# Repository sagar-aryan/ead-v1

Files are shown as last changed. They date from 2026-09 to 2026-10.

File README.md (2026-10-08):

# EAD V1

A right-leg, barefoot wearable for gait research after stroke, built on error
augmentation. Two IMUs on the foot and shank detect every gait cycle; the device
scores each cycle against the wearer's own recorded baseline and, when a step is off,
cues it through six vibration motors on a calf band. A desktop dashboard records the
raw data, manages baselines and sessions, and exports CSV, MATLAB and PDF.

> Research and engineering prototype. Not a medical device and not a validated clinical
> tool.

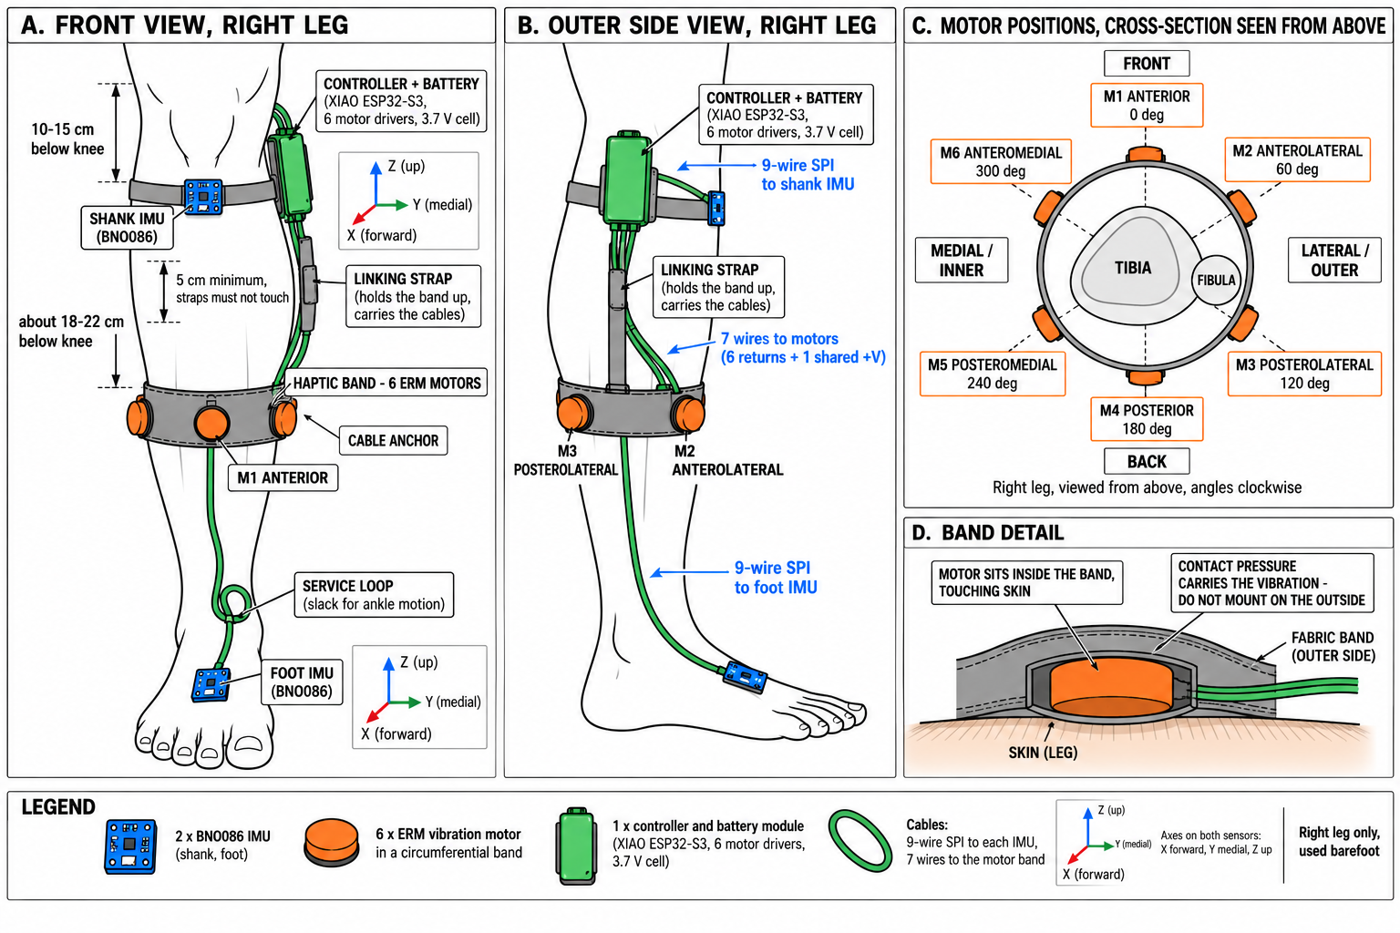
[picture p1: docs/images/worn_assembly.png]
Worn assembly: foot and shank IMUs, controller, and the six-motor calf band


*Illustration of the worn layout and motor positions. Exact placement and wiring:
[`docs/hardware.md`](docs/hardware.md), worn assembly.*

## How it works

```text
foot + shank BNO086 (SPI, 200 Hz)
  → XIAO ESP32-S3: orientation, gait events, zero-velocity updates, per-cycle score
  → vibration cue on the device (no laptop in the loop)
  → Wi-Fi access point or USB → dashboard (Tauri): live view, SQLite store, exports
```

- **Gait:** each right-leg cycle is found from the shank's swing; heel strike, toe-off,
  stance, swing, cadence, stride length and speed are computed on the device, with
  foot-flat zero-velocity updates to bound integration drift.
- **Score:** seven features (swing dorsiflexion, contact angle, inversion/eversion,
  cycle time, stance ratio, stride distance, shank swing rate) are compared with the
  baseline's medians and spreads and combined into one score from 0 to 1.
- **Cue:** a score of 0.35 or more starts a 0.5 s buzz, 60–100 % strength by how far off
  the step was. Where it buzzes names the error, on the side to move away from: the
  back of the calf for too little toe lift or a toe-first landing, the inner side for
  rolling onto the outer edge (inversion), the outer side for rolling in (eversion),
  front and back in turn for timing. The buzz stops at the first good step. On-time limits (5 s
  continuous, 50 % over any 10 s) are enforced on the device; sensor faults, a switched
  off feedback toggle, or 5 s without the laptop hold cues back.
- **Data:** every raw sample is kept. A 6 MB buffer on the device holds about 4.5 min,
  so a Wi-Fi dropout is filled in after reconnecting.

## Hardware

| Part | Detail |
|---|---|
| Controller | Seeed XIAO ESP32-S3 (plain, not Sense) |
| IMUs | 2 × 7Semi BNO086 breakout on SPI: foot (dorsum) and shank (anterior shin) |
| Haptics | 6 ERM coin motors around the calf, driven by the PCB in `hardware/erm-driver-pcb/` (tight variant): low-side MOSFETs, two 3.3 V regulators |
| Power | 1S Li-ion cell, charger module, master switch |

Every pin and connection, with its evidence: [`docs/wiring_reference.md`](docs/wiring_reference.md).
All 15 usable XIAO GPIOs are in use.

## Repository

| Folder | Contents |
|---|---|
| `firmware/` | Device firmware (PlatformIO, Arduino-ESP32); portable, host-tested core in `lib/ead_core` |
| `dashboard/` | Desktop app: Rust backend (device link, SQLite, exports) and React frontend |
| `hardware/erm-driver-pcb/` | KiCad project of the motor driver board, with its own docs |
| `protocol/vectors/` | Golden wire-protocol messages and their generator |
| `tools/` | `eadprobe.py` (independent device client), export checkers, walk replay |
| `recordings/` | Walk recordings with counted steps, used to test gait detection |
| `docs/` | Engineering docs: architecture, implementation, hardware, wiring, protocol, handoff |
| `ead_agent_docs_v2/` | The original V1 specification (read-only) |

## Getting started

**Prerequisites:** PlatformIO, Node.js 20+, a stable Rust toolchain, Python 3 with
pyserial (numpy and scipy for the export checker), and on Linux WebKitGTK 4.1.
`scripts/setup-linux.sh check` reports what is missing. Linux is the tested
platform; setup scripts for macOS and Windows are included.

**Firmware:**

```sh
pio run -d firmware -t upload        # build and flash over USB
python3 tools/eadprobe.py hello      # identity, protocol schema, firmware version
python3 tools/eadprobe.py check      # per-wire sensor check
```

The first build creates `firmware/include/ead_secrets.h` with a random Wi-Fi
passphrase. It is ignored by git; never commit it.

**Dashboard:**

```sh
cd dashboard && npm install
npx tauri dev                        # development
npx tauri build --no-bundle          # release build; see dashboard/README.md for `ead`
```

**Connecting:** over USB, or join the device's access point `EAD-V1-xxxx` (passphrase in
`ead_secrets.h`) and connect the dashboard to `ws://192.168.4.1:8080/ws`.

## Using it

1. **Calibrate:** stand still for 5 s with the sensors strapped on.
2. **Baseline:** walk normally on a straight path until at least 30 valid cycles
   (about 60 steps) are collected. Baselines are versioned per patient and locked.
3. **Check:** a short scored walk against the baseline.
4. **Evaluate:** walk with feedback on; the session's limits (cycles, errors) are set
   first.
5. **Export:** raw samples, cycles, events and cues as CSV, plus `metadata.json`,
   `session.mat` and a PDF report.

Calibrate after every restart. A baseline belongs to the strapping it was recorded
in, so record a new one after re-strapping the sensors.

## Testing

```sh
pio test -d firmware -e native                     # firmware core
(cd dashboard/src-tauri && cargo test)             # backend
(cd dashboard && npm test && npm run build)        # frontend
python3 tools/eadprobe.py vectors                  # protocol, against the golden vectors
```

On hardware, `eadprobe stats` and `cargo test hardware -- --ignored --test-threads=1`.

## Safety

- **Never turn the battery switch on while USB is plugged in.** Motor tests run on
  battery over Wi-Fi with USB unplugged.
- Motors are held off from power-up; GPIO39 must never drive a motor
  ([`docs/wiring_reference.md`](docs/wiring_reference.md) §10).

## Status

Working end to end, worn on battery over Wi-Fi: step detection, per-step scoring
against the wearer's own baseline, directional graded cues, and full raw-data export.
Current state and roadmap: [`docs/handoff.md`](docs/handoff.md).

## Documentation

Start with [`docs/handoff.md`](docs/handoff.md); [`docs/README.md`](docs/README.md)
indexes the rest, including the wire protocol ([`docs/protocol.md`](docs/protocol.md)).

## License

MIT ([`LICENSE`](LICENSE)): firmware, dashboard, tools, hardware design files and
documentation. Exceptions keep their own licences: the IBM Plex fonts in
`dashboard/src-tauri/assets/fonts/` (SIL Open Font License 1.1, `OFL.txt` beside them)
and the agent skills in `.claude/skills/` (Apache 2.0 and MIT, as each states). The
software comes with no warranty, and nothing here is cleared for clinical use.

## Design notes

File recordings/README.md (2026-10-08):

# Recordings

Real device recordings kept as fixtures, so the detector can be changed and
re-checked against measured ground truth instead of against a synthetic signal.

Replay one with:

```
g++ -std=gnu++17 -O2 -I firmware/lib/ead_core/src -I firmware/include \
    -o /tmp/eadreplay tools/replay/main.cpp \
    firmware/lib/ead_core/src/ead/{calibration,mahony,gait,protocol,crc32,cobs,feed}.cpp
/tmp/eadreplay recordings/walk6m-2026-09-18.eadlog --still-seconds 5 --mpu6500
```

A recording made by `eadprobe stats --record` since schema 5 carries the device's
configuration, and the replay converts its counts with it. Older recordings carry
none: `--mpu6500` supplies the MPU6500 build's scales and measured mount maps,
and without it the replay refuses rather than guess. Expected for the walk below:
5 valid cycles, 5.83 m (DEC-022).

| File | Ground truth | Notes |
|---|---|---|
| `walk10m-normal1-2026-10-02.eadlog` | 10.00 m course out and back; right-foot landings 9 out, 9 back | BNO086 build, normal pace. 6,500 frames. |
| `walk10m-normal2-2026-10-02.eadlog` | as above, 9 and 9 | Normal pace. 5,940 frames. Two short steps in the turn. |
| `walk10m-normal3-2026-10-02.eadlog` | as above, 9 and 9 | Normal pace. 6,660 frames. |
| `walk10m-slow-2026-10-02.eadlog` | as above, 11 and 11 | Slow pace. 6,050 frames. |
| `walk10m-fast-2026-10-02.eadlog` | as above, 8 and 8 | Fast pace. 4,770 frames. |
| `walk10m-normal1-2026-10-04.eadlog` | 10.00 m out and back; 8 right-foot landings per leg (walker's count) | Schema 6, 200 Hz, Wi-Fi, barefoot on carpet. `--still-from 8`. Video = data + 9.1 s. |
| `walk10m-normal2-2026-10-04.eadlog` | as above, 8 and 8 | `--still-from 7`. Video = data − 2.9 s. |
| `walk10m-normal3-2026-10-04.eadlog` | as above, 8 and 8 | `--still-from 0`. Video = data − 3.1 s. |
| `walk10m-slow1-2026-10-04.eadlog` | as above, 9–10 per leg; shank swings 10 and 9 | `--still-from 51.5`. Video = data − 2.7 s. |
| `walk10m-slow2-2026-10-04.eadlog` | as above, 9–10 per leg; shank swings 9 and 8 | `--still-from 33`. Video = data − 2.8 s. No stand between the stamps and the walk, or at the far end. |
| `walk10m-fast1-2026-10-04.eadlog` | as above, 7 per leg | `--still-from 37`. Video = data − 2.7 s. No stand at the far end. |
| `walk3min-2026-10-04.eadlog` | back and forth over the 10 m course for about 3 min; no per-leg count | `--still-from 187`. Video = data − 2.6 s. |
| `walk6m-2026-09-18.eadlog` (MPU6500 build: `--mpu6500`) | 6.00 m course, 11–12 alternating steps, 6 right-foot strides | 40 s over Wi-Fi: 5 s standing, the walk, then standing. 4,010 frames, no gaps. Heel strikes at 7.51, 9.17, 10.94, 12.74, 14.33 and 15.92 s; the acceleration peak at 6.95 s that TEST-030 also listed is the first step's push-off (TEST-059). |

The `walk10m-*` files are dashboard sessions written out by
`tools/session2eadlog.py` (TEST-052): the session's configuration, then its raw
frames, so the replay needs no flag. Worn by the developer (ID `DEV-1`), firmware
0.1.0+9c91b7d with the measured BNO086 maps; each starts and ends with about 5 s
standing, and has a stand, a turn and a stand between the legs. Replay with
`--still-seconds 5`, or all of them, with the 2026-10-04 walks, against their counts with
`tools/replay/walks.py /path/to/eadreplay`. Results per engine version are in
TEST-052 onward.

The `2026-10-04` files (TEST-058) start with the walker on the way from the laptop
to the start line, so calibrate from a still window with `--still-from S` (the
first 3 s window the replay accepts). Each walk has three right-heel stamps at the
start line before the first step, for syncing with its video; the stamps are not
steps. The videos are kept off the repository; the offsets above line a frame's
time in the video up with the recording's time.

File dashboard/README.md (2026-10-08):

# EAD V1 Dashboard

Tauri 2 + React + TypeScript + Vite + Rust desktop app for the EAD V1 right-leg
wearable. Contract: `../ead_agent_docs_v2/` docs 08, 10, 11 and 12. Stack
decision: DEC-011.

## Current state

Every doc 11 view except a separate HAPTICS page (cues are shown in CYCLES, EVENTS and
the state bar's vibration switch, DEC-023): LIVE, CYCLES, EVENTS, RAW, REFERENCES,
SESSIONS, EXPORT, DEVICE, and Check (`ead --check`). The Rust backend holds the device link
(USB or Wi-Fi, with backfill), the SQLite store, the session gate, host-side
segments and the export package (CSV, `metadata.json`, `.mat`, PDF).

## Prerequisites

- Node.js 20+ and npm
- Rust stable toolchain
- Tauri 2 Linux dependencies: WebKitGTK 4.1, libsoup 3 (WebView2 on Windows)

## Commands

```sh
npm install
npm run build                      # tsc + vite
(cd src-tauri && cargo build)      # Rust backend
npx tauri dev                      # run the app against the Vite dev server
npx tauri build --bundles deb      # Linux package
npm test                           # frontend logic tests
(cd src-tauri && cargo test)       # backend tests; -- --ignored needs the device
```

## The `ead` command

```sh
npx tauri build --no-bundle
ln -sf "$PWD/src-tauri/target/release/ead-dashboard" ~/.local/bin/ead
```

`ead` then opens the dashboard from any terminal, on the same database as
`tauri dev`. The link follows the build: rerun the first command after pulling
changes. Set up on the development machine on 2026-10-02.

## Icons

`app-icon.svg` is the source. After editing it run `npx tauri icon app-icon.svg`,
then delete the generated `android/`, `ios/`, `Square*Logo.png`, `StoreLogo.png`,
`64x64.png` and `icon.icns`. The app targets Linux and Windows desktops only.

## Data rule

Raw data is canonical and stored in full. Views receive downsampled or summarised
data only (doc 11 §3).

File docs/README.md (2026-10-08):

# EAD V1 — Engineering Documentation

Right-leg, barefoot, wearable error-augmentation system for stroke gait.
Source of implementation truth: `ead_agent_docs_v2/` (read-only contract).
This `docs/` tree records the engineering process: what was built, why, how it
evolved, and what was verified. Update it alongside every significant change.

## Index

- `handoff.md` — Start here: current state, milestone plan, how to run and verify.
- `protocol.md` — The device wire protocol: payloads, framing, backfill.
- `clinical_requirements.md` — The four clinical requirements: where each is
  specified, what is built, what is proven.
- `architecture.md` — Target system design, data flow, interfaces, dependencies.
- `implementation.md` — What exists in code today, per feature.
- `hardware.md` — As-built hardware: the current DEC-016 build, the previous
  MPU6500 build, register config, pins, mount maps.
- `wiring_reference.md` — Every connection of the DEC-016 build, with its evidence.

## Rules for contributors

- Contract values in `ead_agent_docs_v2/` override library defaults and intuition.
  Deviations need a DEC entry.
- Record approaches that were tried and replaced, with the reason.
- Record a test as passed only if it was run; include the measured numbers.
- Mark hardware facts as verified or unverified.

## Agent tooling

Project-level agent skills live in `.claude/skills/` (installed with the
`skills` CLI; pinned in `skills-lock.json`):
- `frontend-design`: UI design guidance.
- `vercel-react-best-practices`: React rendering-performance rules.

## V1 identity (summary)

- Right leg only, barefoot. Two IMUs at 200 Hz (100 Hz before schema 6, DEC-021). The product firmware drives two
  BNO086s on SPI (DEC-016, DEC-017) since schema 5; sessions recorded before it came
  from two MPU6500s on I²C (foot `0x68`, shank `0x69`).
- Six ERM motors on a calf band (DEC-015), fitted on the DEC-016 build (user,
  2026-10-02). Error-driven feedback during evaluations with the dashboard's switch on
  (DEC-023); service-test pulses outside sessions (DEC-018).
- The wire protocol between device and dashboard is implemented three times over
  (firmware, dashboard, `tools/eadprobe.py`), all checked against the same golden
  vectors in `protocol/vectors/`.
- Wi-Fi AP + WebSocket primary link, plus the same binary protocol over USB
  (DEC-005). No BLE, FSR or battery monitoring.
- Desktop: Tauri 2 + React + TypeScript + Rust, for observation, configuration,
  storage, analysis and export.

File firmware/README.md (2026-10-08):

# EAD-V1 Firmware

Seeed XIAO ESP32-S3 with two BNO086 IMUs on SPI (foot and shank) and six ERM motors
through the driver PCB, wired to DEC-016 (`../docs/wiring_reference.md`). Contract:
`../ead_agent_docs_v2/` (`CONFIG_V1.json` holds the fixed values). As-built hardware:
`../docs/hardware.md`. Wire protocol: `../docs/protocol.md`.

## Current state

Acquires both IMUs at 200 Hz, clocked by the foot gyroscope, with each sensor's own
orientation and a native 250 Hz accelerometer stream, and streams the binary
protocol over Wi-Fi and USB. About 4.5 minutes of telemetry is held in PSRAM so a host
can recover anything it missed.

On the device: static calibration, orientation per sensor, gait events from the
shank's swing, ZUPT and stride distance, cycle features, the reference builder, the
error engine and graded directional haptic cues (portable C++ in `lib/ead_core`, also
built on the host for tests and replay). Session kinds CALIBRATION,
REFERENCE_CAPTURE, REFERENCE_CHECK and EVALUATION; SERVICE_TEST pulses single motors
for the Check view.

## Layout

```text
firmware/
  platformio.ini        seeed_xiao_esp32s3 + native test env; gnu++17, no external libs
  include/config_v1.h   fixed V1 values, DEC-016 pins with compile-time checks, mount maps
  lib/ead_core/         portable: codec, COBS, CRC-32, message ring, config section,
                        SH-2 codec, calibration, Mahony, gait, reference builder,
                        error engine, haptics, motor guard
  src/bno086.*          SH-2 over SPI driver for both sensors
  src/acquisition.*     sensor reports, frame assembly
  src/motors.*          motor gates (LOW from boot), service-test pulses
  src/feedback.*        haptic cues during evaluations, on-time limits
  src/telemetry.*       durable message ring (PSRAM) and the processing task
  src/link.*            protocol endpoint: replies, status, streaming, backfill
  src/link_usb.*        USB Serial/JTAG transport (COBS framing)
  src/link_wifi.*       access point + WebSocket transport
  src/device.*          identity, faults, counters, HELLO/STATUS/CONFIG builders
  src/calibration_service.*  still-window calibration
  src/orientation.*     Mahony per sensor, quaternions into each frame
  src/gait_service.*    gait engine, EVENT_BATCH and STEP_BATCH
  src/session_service.* session kinds, reference capture, scoring
  bench/                not product: bno086 (DEC-016 pins), padstate
  test/                 Unity tests, run on the host against the golden vectors
  scripts/              build-time headers (firmware version, AP passphrase)
```

## Build, test and flash

```bash
pio run                 # build for the device
pio test -e native      # unit tests on the host
pio run -t upload       # flash over USB-C
```

## Talking to it

The USB port carries binary protocol frames, not text. Nothing in the firmware
may print to USB: a stray byte would corrupt a frame,
which is why `CORE_DEBUG_LEVEL=0` is a build flag and Arduino `Serial` is unused.

```bash
python3 ../tools/eadprobe.py hello     # identity, sequence window
python3 ../tools/eadprobe.py config    # configuration, hash-verified
python3 ../tools/eadprobe.py stats --seconds 60
```

Expect zero missing frames, zero dropped, zero rejected, and |a| ≈ 1.02 g on a
resting device.

## Wi-Fi access point

`EAD-V1-<last two MAC bytes>`, WPA2, channel 6, device at `192.168.4.1`,
WebSocket at `ws://192.168.4.1:8080/ws`. The passphrase is generated at first
build into `include/ead_secrets.h`, which git does not track; delete that file to
roll a new one.

## Wiring

DEC-016, every pin with its evidence: `../docs/wiring_reference.md`. Motors M1–M6 on
GPIO 4, 6, 42, 5, 2, 1 (DEC-029), held LOW as the first action at boot.

## Mount maps

`anat = M · chip`, applied to accel and gyro. Per-sensor maps are
measured on the leg (TEST-051) and kept in `include/config_v1.h`. A map that is not a
proper rotation fails to compile (DEC-009).

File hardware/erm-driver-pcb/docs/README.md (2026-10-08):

# EAS V1 — Six-Channel ERM Driver PCB

A single-sided, SMD-only, drill-free driver board for six 3 V ERM vibration motors in the EAS wearable. Two HT7833 LDOs make two isolated 3.3 V motor rails; six IRLML6344 low-side switches take PWM from a separate XIAO ESP32-S3. The specification is in `../EAS_ERM_Driver_PCB_Handoff/`; this folder records how it was implemented.

**In the EAD V1 repository since 2026-10-05** (`hardware/erm-driver-pcb/`), copied from
`~/Documents/ead pcb/` without the purchase invoices and KiCad's per-user files. The
**tight variant** (`EAS_ERM_Driver_tight/`, 36.07 × 27.60 mm) is the board fitted on
the device (user, 2026-10-05). The device as a whole is described in `../../../docs/`
(`hardware.md`, `wiring_reference.md`); the notes below are this board's own record,
as written.

## Status (2026-09-22)
- **Four layout variants, all verified in software:** ERC 0, DRC 0 violations, 0 unconnected, 0 schematic-parity issues, and every `check.py` handoff check passes.
- **The tight variant is built and drives the six motors on the device.**

| Variant | Folder | Board | Layout | 0 Ω jumpers |
|---|---|---|---|---|
| Single row (original) | `EAS_ERM_Driver/` | 82.75 × 19.00 mm (1572 mm²) | one row of 6 channels (DEC-013) | **none** |
| Compact | `EAS_ERM_Driver_compact/` | **44.70 × 32.60 mm** (1457 mm²) | two rows of 3 channels (DEC-016) | **none** |
| Mini | `EAS_ERM_Driver_mini/` | **38.91 × 29.28 mm** (1139 mm²) | two rows of 3, relaxed rules (DEC-017) | **none** |
| Tight | `EAS_ERM_Driver_tight/` | **36.07 × 27.60 mm** (996 mm²) | mini + 0.3 mm gaps and tight courtyards (DEC-018) | **none** |

All variants share the same circuit, parts and schematic content. Single row and compact also share footprints and rules and differ only in layout. The mini uses the standard (smaller) lands, a 0.4 mm gap around wire pads, a 0.5 mm edge margin and 1.0 mm power trunks (user-approved). The tight variant additionally uses 0.3 mm copper gaps and tight part courtyards. Choose one to fabricate.

| Common item | Value |
|---|---|
| Copper | one layer (F.Cu); no vias, no holes, no jumpers |
| Parts | 46 SMD parts + 18 SMD wire pads (no connectors) |
| Etch rules | 0.4 mm minimum track and gap; 0.5 mm pour clearance. Single row / compact: 0.6 mm around wire pads, 1.0 mm copper-to-edge, 1.5 mm power trunks, hand-solder lands. Mini: 0.4 mm, 0.5 mm, 1.0 mm, standard lands |

## Power rails
| Net | Source | Feeds | Copper |
|---|---|---|---|
| `SWITCHED_SYSTEM+` | wire pad `PWR+`, from the external master switch on the MCP73833 LOAD+ side (never raw BAT) | U1 and U2 VIN (SOT-89 tab), pad `ESP+` | 1.5 mm strip up the left edge (single row: also along the top edge to U2; mini: 1.0 mm) |
| `HAPTIC_3V3_A` | U1 HT7833 | motors 1–3 (pad `A+`), C5 1 µF, C7 220 µF, C15–C17 100 nF | 1.0 mm bus |
| `HAPTIC_3V3_B` | U2 HT7833 | motors 4–6 (pad `B+`), C6 1 µF, C8 220 µF, C18–C20 100 nF | 1.0 mm bus |
| `GND` | wire pad `GND` | everything | 1.5 mm bus under each channel row (mini: 1.0 mm), a 1.0 mm tooth per channel (mini: 0.8 mm), and pour (compact and mini: the two row buses are joined down the right edge) |

The two 3.3 V rails are never connected on the board. `check.py` confirms this, and DRC would flag any short.

## Wire pad map
Labels are as printed on the assembly drawings. Positions are pad centres in mm from the top-left corner of the outline.

| Drawing label | Ref | Net | Connect to | Pad (mm) |
|---|---|---|---|---|
| `PWR+` | J1 | SWITCHED_SYSTEM+ | master switch output (charger LOAD+ side) | 3.0 × 2.5 |
| `GND` | J2 | GND | charger LOAD− / system ground | 3.0 × 2.5 |
| `ESP+` | J3 | SWITCHED_SYSTEM+ | XIAO **battery** input (`ESP_SW_BAT+`). **Not** the XIAO 3V3 pin | 2.0 × 2.0 |
| `EGND` | J4 | GND | XIAO GND | 2.0 × 2.0 |
| `PWM1`…`PWM6` | J5–J10 | PWM1–6 | XIAO GPIOs | 2.0 × 2.0 |
| `A+` | J11 | HAPTIC_3V3_A | + leads of motors 1–3 (up to 3 wires) | 2.5 × 7.0 |
| `M1-`…`M3-` | J12–J14 | M1-…M3- | − lead of motors 1–3 | 2.5 × 2.5 |
| `B+` | J15 | HAPTIC_3V3_B | + leads of motors 4–6 (up to 3 wires) | 2.5 × 7.0 |
| `M4-`…`M6-` | J16–J18 | M4-…M6- | − lead of motors 4–6 | 2.5 × 2.5 |

Pad centres (mm from the top-left corner of the outline; each variant's full list is in its `output/check.txt`):

| Pads | Single row | Compact | Mini | Tight |
|---|---|---|---|---|
| J1 `PWR+`, J2 `GND` | (2.5, 16.8), (6.2, 16.8) | (2.5, 30.4), (6.2, 30.4) | (2.0, 27.5), (7.8, 27.5) | (2.0, 25.9), (7.6, 25.9) |
| J3 `ESP+`, J4 `EGND` | (2.0, 14.2), (9.2, 17.0) | (2.0, 27.9), (9.2, 30.6) | (4.9, 26.4), (10.7, 27.8) | (4.8, 24.8), (10.4, 26.1) |
| `PWM1`–`PWM3` | y 14.9; x 16.7, 26.1, 35.6 | y 13.0; x 16.7, 26.1, 35.6 | y 12.0; x 14.8, 22.9, 31.1 | y 11.3; x 14.1, 21.5, 28.9 |
| `PWM4`–`PWM6` | y 14.9; x 55.0, 64.4, 73.9 | y 28.5; x 16.7, 26.1, 35.6 | y 26.4; x 14.8, 22.9, 31.1 | y 24.8; x 14.1, 21.5, 28.9 |
| `A+` | (13.4, 6.7) vertical | (13.4, 4.8) vertical | (10.2, 4.0) vertical | (9.8, 4.0) vertical |
| `M1-`–`M3-` | y 9.9; x 16.8, 26.2, 35.6 | y 8.1; x 16.8, 26.2, 35.6 | y 7.2; x 15.6, 23.7, 31.8 | y 6.9; x 14.5, 21.9, 29.4 |
| `B+` | (59.7, 2.2) horizontal | (13.4, 20.3) vertical | (10.2, 18.3) vertical | (9.8, 17.4) vertical |
| `M4-`–`M6-` | y 9.9; x 55.0, 64.5, 74.0 | y 23.6; x 16.8, 26.2, 35.6 | y 21.6; x 15.6, 23.7, 31.8 | y 20.4; x 14.5, 21.9, 29.4 |

- **Board edge:** only the four power/ESP-power pads sit at the edge. The PWM and M- pads are enclosed by a GND or rail trace, so their wires pass over that trace (DEC-003). Use insulated wire and glue it down for strain relief.
- **Channel mapping:** PWMn drives Mn- (n = 1…6). The motor sits between A+ (or B+) and its Mn- pad.

## Rebuild and verify
```bash
cd EAS_ERM_Driver && bash scripts/export.sh            # single-row variant
cd EAS_ERM_Driver_compact && bash scripts/export.sh    # compact variant
cd EAS_ERM_Driver_mini && bash scripts/export.sh       # mini variant
cd EAS_ERM_Driver_tight && bash scripts/export.sh      # tight variant
```
Each run rebuilds from its own `scripts/build.py`, then runs ERC, DRC+parity, `check.py` and all exports, and stops on any failure.
- **Requirements:** KiCad 10.0.6 (`kicad-cli` and the `pcbnew` Python module), Python 3, poppler `pdftoppm`, Pillow.
- **To inspect:** open `EAS_ERM_Driver*.kicad_pro` in KiCad 10; the files are not readable by KiCad ≤ 9.

## Outputs (`<variant folder>/output/`, file names prefixed with the project name)
| File | Use |
|---|---|
| `*_TONER_F.Cu_MIRRORED_print_1to1.pdf` | **print this for toner transfer**, at 100 % scale (one copy) |
| `*_TONER_PANEL_6up_MIRRORED_print_1to1.pdf` | tight and mini variants: six copies on one A4 sheet, 30 mm apart, with a printed ruler to confirm the print scale (DEC-020). Any other grid: `scripts/panel.py <cols> <rows> [gap mm]` (it is not produced by `export.sh`, which clears `output/`) |
| `*_PANEL.kicad_pcb` | throwaway board the panel PDF is plotted from; regenerate it with `scripts/panel.py`, never edit it |
| `*_F.Cu_top_view_fitcheck_1to1.pdf` | unmirrored top view; lay the real parts on it before etching |
| `*_placement_3to1.pdf` | **place parts from this one**: part outlines, reference + value, pad labels and legend, without pad numbers |
| `*_assembly_1to1.pdf`, `*_assembly_3to1.pdf` | the same drawing with the pads and their pin numbers sketched; use it to identify pin 1 on U1/U2 and Q1–Q6. The pad digits overlap some labels, which is why `*_placement_3to1.pdf` exists |
| `*_schematic.pdf` | schematic |
| `*_bom.csv` | BOM |
| `gerbers/` | F.Cu and Edge.Cuts Gerbers (no drill file: zero holes) |
| `erc.rpt`, `drc.rpt`, `check.txt` | verification reports; `check.txt` contains the full connection summary and pad map |
| `preview_*.png` | quick-look images |

## Documentation index
- `architecture.md`: system and board structure.
- `implementation.md`: how the build scripts generate the design.
- `hardware.md`: BOM, pinouts, footprints, thermal, fabrication and assembly.
- `decisions.md`: DEC-001…DEC-020.
- `handoff.md`: how to continue.

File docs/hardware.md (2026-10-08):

# Hardware (as built)

Contract values come from `ead_agent_docs_v2/02_HARDWARE_WIRING.md`,
`03_GPIO_PIN_MAP.md` and `17_HARDWARE_BOM_AND_OWNED_PARTS.md`. This file records
what the physical unit actually is, how it deviates, and what has been verified.
Every row states its evidence; "unverified" means nobody has measured it yet.

## Current build: DEC-016 (2026-10-02)

| Item | State | Evidence |
|---|---|---|
| Wiring | DEC-016 exactly: two BNO086 on SPI, six motor channels, two HT7833 rails, battery. Every connection in `docs/wiring_reference.md` §3–§11 | User, 2026-10-02, against `EAD_V1_XIAO_connections.pdf` (whose pins match DEC-016) |
| Parts fitted | Everything, including the six motors | User, 2026-10-02 |
| Motors | Tested by the user with a PWM signal | User, 2026-10-02 |
| Powered | Yes, since assembly | User, 2026-10-02 |
| Which XIAO | The one measured in TEST-041: USB serial number (= MAC) `44:B1:76:AF:FB:7C` | Read from the USB descriptor, 2026-10-02 |
| Firmware on it | The product firmware, schema 5 (`5b8dd28` and later), on the DEC-016 pins. Before that, `padstate`, which booted on the new wiring (TEST-044) | HELLO, 2026-10-02 |
| ERM driver | Separate PCB, `hardware/erm-driver-pcb/` (`~/Documents/ead pcb/` until 2026-10-05), the **tight variant** fitted (`EAS_ERM_Driver_tight/`, 36.07 × 27.60 mm; user, 2026-10-05): Holtek HT7833 SOT-89 ×2, IRLML6344 ×6, 1N5819W, 100 Ω / 100 kΩ, 10 nF across each motor, 100 nF per channel. Motors rated 3 V, 90 mA, 120 mA at start. Its bring-up on 2026-09-24 ran the motors at 20 kHz PWM from GPIO1–6 (`erm_channel_test.ino`); a stuck-motor event there has no established root cause | PCB project docs |
| Measured on the assembled build | Both BNO086s pass every wiring, identity and data check at 1 MHz (TEST-043). Pad readback: GPIO42 (motor 3) read low, unlike the other five; MTMS measured about 100 kΩ to GND (user), the correct gate network | TEST-043, TEST-044, user |
| XIAO power | The switched LOAD+ feeds the ERM driver's PWR+ **and the XIAO's 5V (VUSB) pin**, not its BAT+ pad. **The XIAO has no diode on that pin**, so with USB plugged in, USB 5 V sits on the switched node: switch OFF, it powers the ERM driver (motor rails live); switch ON, it meets the charger's LOAD+ | User, 2026-10-02; Seeed XIAO ESP32-S3 wiki |
| Foot cable | About 30 cm | User, 2026-10-02 |
| Charger | SmartElex MCP73833 module (Robocraze): USB mini-B, 500 mA default charge, separate battery and load connectors. The cell has its own protection board (user, 2026-10-04) | User, 2026-10-02 and 2026-10-04; product page |

**Only firmware on the DEC-016 pins goes on this build:** the product firmware from
`5b8dd28` on, `firmware/bench/bno086`, or `padstate`. Product firmware from before
`5b8dd28` uses the doc-03 pins: it would run I²C bus recovery and `Wire` on GPIO5/6
(motor gates 5 and 6) and drive GPIO9 (MOSI), 43 and 44 (both chip selects) LOW as
motors.

`padstate` is not harmless on this build either: at each boot its readback switches
each pin's internal pull-up on for 0.3 ms, which on a motor pin puts about 2.3 V on
the gate (the DEC-016 GPIO39 reasoning) and switches that MOSFET on for 0.3 ms. That
is far too short to spin an ERM.

The sections below describe the previous build (MPU6500 on I²C, 2026-09-17 to
2026-10-01), on which every recording and dashboard session so far was made.

## Controller

| Item | Value | Evidence |
|---|---|---|
| Board | Seeed XIAO ESP32-S3 | PlatformIO env `seeed_xiao_esp32s3` |
| Flash / PSRAM | 8 MB / 8 MB (OPI) | Board definition (`-DBOARD_HAS_PSRAM`, `qio_opi`); PSRAM present on this unit (`eadprobe hello`: `psram_ring`) |
| USB | Native USB Serial/JTAG, VID:PID `303a:1001`, serial number = Wi-Fi MAC `44:B1:76:AF:FB:7C` | `lsusb` / `udevadm`, 2026-09-17 |
| Partition table | `default_8MB.csv`: 2 × 3.2 MB app slots, 1.5 MB data (`spiffs`), 64 KB coredump | Arduino-ESP32 2.0.17 package |
| Wi-Fi antenna | Seeed recommends fitting the supplied U.FL antenna for usable Wi-Fi range | Seeed wiki (accessed 2026-09-17) |
| Power | Battery-powered and wearable (user, 2026-09-17). Firmware has no battery or charger logic (spec) | User statement |

## IMUs (previous build)

Both breakouts were sold as MPU6050 but carry **MPU6500** silicon.

| Sensor | I²C address | WHO_AM_I | Evidence |
|---|---|---|---|
| Foot (dorsum) | `0x68` (AD0 → GND) | `0x70` | Boot log 2026-09-17 |
| Shank (anterior shin) | `0x69` (AD0 → 3V3) | `0x70` | Boot log 2026-09-17 |

Register configuration written at boot and verified by readback on both sensors
(boot log + `c` diagnostics, 2026-09-17):

| Register | Address | Value | Meaning |
|---|---|---|---|
| PWR_MGMT_1 | 0x6B | 0x01 | Awake, PLL clock source |
| SMPLRT_DIV | 0x19 | 0x09 | 1 kHz / 10 = 100 Hz output |
| CONFIG | 0x1A | 0x03 | Gyro DLPF ≈ 41–42 Hz |
| ACCEL_CONFIG2 | 0x1D | 0x03 | Accel DLPF ≈ 41 Hz (MPU6500 only) |
| GYRO_CONFIG | 0x1B | 0x08 | ±500 °/s, 65.5 LSB/(°/s) |
| ACCEL_CONFIG | 0x1C | 0x08 | ±4 g, 8192 LSB/g |
| INT_PIN_CFG | 0x37 | 0x00 | Active-high, push-pull, 50 µs pulse |
| INT_ENABLE | 0x38 | 0x01 | Data-ready interrupt |

Observed at rest on a desk (not worn), 78 samples over 7.8 s, 2026-09-17:
foot |a| = 1.024 g, shank |a| = 1.014 g, accel σ ≤ 0.002 g, gyro offsets up to
3.1 °/s (foot X) and 2.0 °/s (shank Y). The offsets are ordinary MEMS gyro bias;
startup calibration (milestone M3) removes them.

## Pin map of the previous build (doc 03)

The current build's pin map is DEC-016, in `docs/wiring_reference.md` §3.

| Function | XIAO pin | ESP32-S3 GPIO | Status |
|---|---|---:|---|
| I²C SDA | D4 | 5 | Verified: both IMUs enumerate |
| I²C SCL | D5 | 6 | Verified: both IMUs enumerate |
| Foot IMU INT | D8 | 7 | Verified (TEST-015) |
| Shank IMU INT | D9 | 8 | Verified (TEST-015) |
| Motor 1 PWM | D0 | 1 | Held LOW (MPU6500 build) |
| Motor 2 PWM | D1 | 2 | Held LOW (MPU6500 build) |
| Motor 3 PWM | D3 | 4 | Held LOW (MPU6500 build) |
| Motor 4 PWM | D10 | 9 | Held LOW (MPU6500 build) |
| Motor 5 PWM | D6 | 43 | Held LOW (MPU6500 build) |
| Motor 6 PWM | D7 | 44 | Held LOW (MPU6500 build) |

## Sensor mounting and axis maps

The anatomical frame (doc 04 §1) is X forward toward the toes, Y medial (left for
the right leg), Z up. It is right-handed, and so is the MPU chip frame, so each
sensor's chip → anatomical map must be a proper rotation (determinant +1).
`firmware/include/config_v1.h` stores the maps as signed-permutation matrices and
rejects anything else at compile time.

| Sensor | Physical mounting | Map (anat = M · chip) |
|---|---|---|
| Foot | Flat on the dorsum, chip X toward the toes, chip Z up | Identity |
| Shank | Strapped to the anterior shin; chip +Z toward the bone (posterior); chip +X up the leg | `X = −chipZ`, `Y = +chipY`, `Z = +chipX` |

Derivation of the shank map: measured on the leg (TEST-027, 2026-09-17). Under the
previous map (`X = −chipZ`, `Y = +chipX`, `Z = −chipY`) standing still put gravity
on anatomical Y (+0.99 g) and a seated knee extension turned about anatomical Z
(+43 °/s) — anatomical Y and Z were interchanged. Correcting the measurement
(`Z_true = Y_measured`, `Y_true = −Z_measured`) gives the map above, which is still
a proper rotation. The earlier derivation assumed chip +Y points down the leg; the
board is in fact strapped with chip +X up the leg.

**Placement image.** `reference_images/RIGHT_LEG_IMU_PLACEMENT.png` sets the
anatomical convention; the shank board's chip axes in this table are the as-built
record, measured on the leg (DEC-009).

**Verification status.** Compile-time proper-rotation checks pass, including a
negative test with a reflected map. The shank map above was measured on the leg
(TEST-027) and flashed; re-running the mounting check with it is the confirmation
step. The foot map was confirmed on the leg: gravity dominant on +Z, the board
tilted about 33° on the instep, which calibration removes.

### BNO086 boards (DEC-016 build)

The table above is the MPU6500 build. The BNO086 maps were measured on the leg
(TEST-051, 2026-10-02) and agree with the user's description of the silkscreen
axes as worn:

| Sensor | Described by the user | Measured map (anat = M · chip) |
|---|---|---|
| Foot | chip x medial, chip y back toward the shank, chip z up | `X = −chipY`, `Y = +chipX`, `Z = +chipZ` |
| Shank | chip z out of the shin, chip x medial, chip y up the leg | `X = +chipZ`, `Y = +chipX`, `Z = +chipY` |

The foot board sits about 42° off level on the instep (standing gravity
(0.29, 0.62, 0.76) g in the chip frame); calibration removes the tilt.

## Haptics

**Current (DEC-016 build):** the six ERM channels and motors are fitted on the
separate driver PCB (user, 2026-10-02) and all six were felt at 50 % duty in service
pulses (TEST-049). The firmware drives the motor GPIOs LOW first in `setup()`, then
runs 200 Hz PWM for service pulses (DEC-018) and feedback cues during evaluations
(DEC-023). Cues were felt while walking on battery over Wi-Fi (TEST-066); since
DEC-026 cues run 60–100 % (153–255) for 500 ms.

**History:** on the MPU6500 build the channels were not fitted (user, 2026-09-17), and
DEC-006 kept all PWM and haptic code out of the firmware until they were.

## Hardware notes

- **Sensor ranges:** the BNO086 build runs at ±8 g and ±2000 °/s (TEST-040).

## BNO086 bench test (one sensor, SPI)

A single BNO086 breakout (7Semi, CEVA/Hillcrest SH-2) wired to a XIAO ESP32-S3 for
bring-up. Edge pins only, so nothing has to be soldered to the pads under the board.
This is the bench layout; it is not the product pin map, because D0–D3 are the
motor outputs in the product.

| Function | XIAO pin | ESP32-S3 GPIO |
|---|---|---:|
| 3V3 | 3V3 | — |
| GND | GND | — |
| SPI SCK | D8 | 7 |
| SPI MISO | D9 | 8 |
| SPI MOSI | D10 | 9 |
| CS | D3 | 4 |
| INT | D2 | 3 |
| RST | D1 | 2 |
| WAKE (= PS0 net on this board) | D0 | 1 |

PS0, PS1, BOOT, SDA, SCL and both Qwiic connectors are left unconnected. The board's
PS0/PS1 solder jumpers were opened by the user, so the on-board pull-ups hold both
high at reset and the part comes up in SPI mode; its I²C connectors no longer work.
WAKE and PS0 are the same net, so WAKE must be driven high before reset is released,
or the part would latch a UART mode instead.

Measured on this board, 2026-09-23 (TEST-039):

- Line readback (ESP32 pull-up / pull-down, sensor held in reset): CS 1/0 (floating,
  as expected); SCK, MISO and MOSI all 1/1, because on the BNO086 those are the same
  chip pins as SCL, SDA and SA0, which carry the breakout's I²C pull-ups. 0/0 on any
  line would mean it is held low: a short to ground or a wire on the wrong pin.
- INT is high while RST is held low, and goes low 112–115 ms after reset is released.
- SH-2 opens at 3 MHz, SPI mode 3.
- Product ID: 4 entries, the application firmware being part 10004563, version
  3.12.6, build 62, reset cause 4 (external reset — the RST pulse).
- Feature probe: ARVR-stabilised RV, gyro-integrated RV, stability classifier,
  magnetometer and tap detector all accept a set-feature request.
- Pulling WAKE low with no reports enabled made the sensor assert INT within 1 ms.
- At rest: |a| = 9.752 m/s² over 249 accelerometer reports, |ω| = 0.005 rad/s over
  199 gyro reports. Rotation vector, accelerometer and gyro stream together at
  99.9 Hz (2952 samples over 29.5 s).
- The product uses the game rotation vector (6-axis), which needs no magnetometer:
  tilt is referenced to gravity, heading is relative.

### What the BNO086 says about its own hardware (TEST-040, 2026-09-23)

| Reading | Value |
|---|---|
| Accelerometer | `Bosch Sensortec BMA280`, range 20082 (Q8 → 78.4 m/s² = ±8 g), q = 8 |
| Gyroscope | `Bosch Sensortec BMI055`, range 17863 (Q9 → 34.9 rad/s = ±2000 °/s), q = 9 |
| Magnetometer | `Bosch Sensortec BMM150`, range 32000, q = 4 |
| Rotation vector | range 16384, q = 14 |
| Oscillator | external crystal |
| FRS serial number | record present, empty |
| Interactive Calibration (BNO086 only) | Motion Intent accepted, Motion Request report accepted |
| Accelerometer resolution | 1120 steps per g over ±8 g = 14.1 bits (14-bit fusion is BNO086 only) |

Raw accelerometer counts come out as multiples of 4: the BMA280's 14-bit value sits
left-aligned in a 16-bit field.

### The bench project on the DEC-016 wiring (2026-10-02)

The one-sensor bench wiring above no longer exists: the user reported on
2026-10-02 that the XIAO is now wired to DEC-016 with everything soldered. On that
wiring the old bench pins D0, D1 and D3 are motor gates 1, 2 and 4, so
`firmware/bench/bno086` was moved to the DEC-016 pins:

- One sensor per build: `-e foot` (CS GPIO43, INT GPIO39) or `-e shank` (CS GPIO44,
  INT GPIO40); RST GPIO41 and WAKE GPIO3 are shared. The SparkFun library cannot
  drive two sensors at once: its pins are file-scope globals and CEVA's `sh2.c`
  inside it has one global instance (read in the library source, v1.0.6).
- First action: the six motor gates (GPIO1, 2, 42, 4, 5, 6) LOW, then both CS high.
  A `static_assert` refuses any build that puts a sensor line on a motor pin.
- SPI at 1 MHz (`docs/wiring_reference.md` rule 5), not the 3 MHz used on the bench.
- Also reports whether the other sensor's INT is high in reset and low after the
  shared RST is released, without talking to it.

Run on hardware: both sensors pass (TEST-043).

## Connection reference

`docs/wiring_reference.md` carries every electrical connection in one place:
the XIAO's full pin map, both BNO086 pinouts, the six ERM motor channels, the
haptic rails, the harnesses and the power input, each connection marked with
the evidence behind it. It is the document to hand to whoever builds the board.

## Worn assembly (DEC-015)

Worn assembly: foot IMU, shank IMU, controller and the six-motor band

*`docs/images/worn_assembly.png`. Illustration of the worn layout. As built: the
controller sits on the outer side of the right leg (panel B); the motor cable has 8
wires, since each half of the band has its own positive rail
(`docs/wiring_reference.md` §11). Checked against the contract: the six motor angles
and their clockwise order, the fibula on the lateral side, M2 toward the toes and M3
toward the calf in the side view, and both sensor axis triads.*

Two separate straps on the right shank, plus the foot module; worn on battery over
Wi-Fi since 2026-10-05 (TEST-066).

| Item | Position | Notes |
|---|---|---|
| Shank IMU (BNO086) | Anterior shin, 10–15 cm below the knee, on the upper strap | Doc 01 §2 |
| Controller + battery | Lateral side of the same upper strap | Position not specified by the contract; chosen to keep every cable short except the foot run |
| Six ERM motors | Lower strap, around the fullest part of the calf, below the upper strap | Angles per doc 06 §7: M1 anterior 0°, then clockwise viewed from above |
| Foot IMU (BNO086) | Dorsum of the foot, midfoot, lying flat | Doc 01 §2 |

Cable runs: 9 conductors to the shank IMU (3V3, GND, SCK, MISO, MOSI, CS, INT,
RST, WAKE), 10 to the foot IMU (the same plus a second ground beside SCK, for
the long run), and **8 to the motor band**: six switched returns, one positive
from haptic rail A for M1–M3, and one from rail B for M4–M6. The two rails come
from separate regulators whose outputs must never be joined
(`ead_agent_docs_v2/02_HARDWARE_WIRING.md` §5). An earlier revision said 7 with
one shared positive; that would have tied the two regulator outputs together.

Practical points for the build, none of them yet verified on a leg:

- Leave at least 5 cm between the two straps, and do not let them touch: touching
  straps couple vibration mechanically, on top of what travels through tissue.
- The calf tapers below its fullest point, so the motor band will tend to slide
  down. A short vertical strap between the two bands, doubling as the cable
  channel, holds it up.
- Anchor the foot cable to the **motor** band before it runs down the shin. A tug
  on that cable must not reach the IMU strap, because rotating that strap
  invalidates the shank mount map mid-session.
- Keep the controller enclosure on the lateral side, off the tibia, and tight
  enough not to bounce; its mass sits on the same strap as the IMU.
- Leave slack in the strap-to-strap wiring: calf circumference changes as the
  muscle contracts.

## Power budget (estimate, 2026-10-05; not measured)

The battery switch is never ON while USB is plugged in (user, 2026-10-05), so the
battery current can only be measured in series with the cell, or as a runtime test.

| Load | Current at the battery | Source |
|---|---|---|
| XIAO ESP32-S3, Wi-Fi AP streaming ~23 kB/s, CPU 240 MHz (firmware sets neither clock nor TX power) | 100–150 mA average; TX bursts to ~340 mA | Seeed wiki: ~100 mA Wi-Fi active; Espressif ESP32-S3 datasheet ranges for TX/RX |
| BNO086 ×2, accelerometer + gyroscope + game rotation vector at 200 Hz | 10–15 mA each | ~12.3 mA awake measured by a third party (wolles-elektronikkiste.de); our report set not measured |
| ERM ×6 via HT7833 (LDO, so battery current ≈ motor current) | 90 mA rated per motor at 3 V, 120 mA start; × PWM duty × on-time | `docs/hardware.md` ERM driver row |
| Cues (DEC-023): 250 ms per ~1.2 s cycle | typical ~3 mA (one motor, ~50 % duty, 30 % of steps); worst ~30 mA (two motors, 80 %, every step) | arithmetic |

Totals: ~125–190 mA streaming without cues, ~155–220 mA at worst-case feedback; peak
~610 mA. With 1.6–1.8 Ah usable from a ~2 Ah cell: **about 8–14 h** without cues,
**7–12 h** at worst-case feedback.

To be confirmed by measurement: the usable capacity (the XIAO's 3.3 V regulator is fed
from the 5V pin at cell voltage), the cell's real capacity, and the AP-mode average. A runtime test settles it: full charge, stream over Wi-Fi with
the dashboard recording until the device stops; the session's last frame is the runtime.

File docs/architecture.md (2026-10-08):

# Architecture

This is the target design. What is implemented today is tracked in
`docs/implementation.md`; as-built hardware facts are in `docs/hardware.md`.

## Overview

EAD V1 is a right-leg, barefoot, wearable error-augmentation system for gait
monitoring and retraining after stroke (`ead_agent_docs_v2/01_SYSTEM_SPEC.md`).
Two IMUs (foot + shank) feed a 200 Hz real-time loop on a XIAO ESP32-S3 (100 Hz
before schema 6). Orientation comes from each BNO086's own fusion (game rotation
vector, DEC-021; Mahony 6-DoF on the ESP32 before schema 6). The loop detects gait events, applies
foot-only ZUPT correction, and scores each gait cycle against a patient-specific
reference. A Tauri 2 desktop dashboard observes, configures, records, analyses
and exports; it never closes a control loop.

Haptic feedback runs on the device during an EVALUATION session with the dashboard's
master switch on: one cue per scored cycle, after the step lands (DEC-023). Outside a
session the motors run only as service-test pulses (DEC-018).

The hardware is the DEC-016 build: two BNO086 on SPI plus six motor channels on a
separate ERM driver board, with the haptic band on the calf (DEC-015). The product
firmware supports it since schema 5 (DEC-017). The MPU6500/I²C build it replaced is
described at the end of the components, because every recording before 2026-10-02
came from it.

## Components

### Foot and shank sensors (BNO086, DEC-016/017)
- Foot: dorsum of the right foot; CS GPIO43, INT GPIO39. Shank: anterior shin,
  10–15 cm below the knee; CS GPIO44, INT GPIO40.
- One SPI bus (SCK 7, MISO 8, MOSI 9, 1 MHz, mode 3); RST (41) and WAKE (3) shared.
- Calibrated accelerometer (±8 g, 250 Hz), gyroscope (±2000 °/s, 200 Hz) and game
  rotation vector (200 Hz) reports, read on INT by our own SH-2 code
  (`src/bno086.cpp`, `lib/ead_core/src/ead/sh2.cpp`); rates from TEST-054.
- Mount maps: measured on the leg (TEST-051; DEC-009: per sensor).

### Haptic band
Contract: six ERMs around the lower shank (moved to the calf by DEC-015), low-side
IRLML6344 switches on GPIO 1, 2, 4, 9, 43, 44 (doc 03; GPIO 1, 2, 42, 4, 5, 6 under
DEC-016), 200 Hz PWM limited to 20–80 % duty, 5 s maximum on-time,
50 % rolling duty over 10 s. Current build: all six motor GPIOs are driven LOW at boot;
they are driven by a service-test pulse (DEC-018) or a feedback cue (DEC-023), each
timed on the device and held to those limits by one `MotorGuard`.

### ESP32-S3 real-time controller
- **Acquisition** (core 1, highest priority): each sensor's INT (IRAM-safe handler)
  timestamps its packet; the task reads it over SPI within the 1 ms rule, gives each
  sample its own time from the SH-2 timestamps, and emits a frame per foot gyroscope
  sample with the shank's latest. It also runs the per-wire sensor check at boot and on
  request (SERVICE_TEST).
- **Processing** (core 1): calibration, orientation, gait state machine and
  events, ZUPT, cycle features, reference builder/loader, error score, classes
  and confidence. Portable C++ in `lib/ead_core`, also built on the host for
  deterministic replay tests.
- **Links** (core 0): Wi-Fi access point serving the WebSocket endpoint, and USB
  carrying the same binary messages (DEC-005). A PSRAM ring keeps recent
  telemetry so a reconnecting dashboard can backfill gaps.
- **Device states** (doc 07 §6): BOOT, SELF_TEST, CALIBRATING,
  REFERENCE_CAPTURE, READY, RUNNING, PAUSED, FAULT, RECOVERY. A reference check
  runs in REFERENCE_CAPTURE; RUNNING is an evaluation session only (DEC-008).
- **Priority:** acquisition > safety/fault checks > gait/orientation > storage >
  links. Links never block acquisition.
- **Motors** (`src/motors.cpp`): LEDC at 200 Hz, 8 bit; a pulse is accepted by the
  portable `MotorGuard` and ended by an `esp_timer`, so it stops whatever the link does.
- No battery, charger, switch, BLE or FSR code (contract).

### Previous build: MPU6500 on I²C (until 2026-10-01)
Foot `0x68` (INT GPIO7, identity map) and shank `0x69` (INT GPIO8, map
`X = −chipZ, Y = +chipY, Z = +chipX`, measured in TEST-027) on one I²C bus (GPIO5/6,
400 kHz), ±4 g, ±500 °/s, 42 Hz DLPF, frames clocked by the foot data-ready interrupt.
Its sessions store configuration format 1; the replay tool reads them with `--mpu6500`.

### Dashboard (Tauri 2 + React + TypeScript + Rust)
- **Rust backend:**
  - protocol codec;
  - link layer (WebSocket, USB);
  - device manager (handshake, keepalive, command acknowledgements, gap
    backfill);
  - SQLite store (patients, references, sessions, segments, raw frames with
    min/max summaries, cycles, events);
  - 20 Hz live aggregation;
  - exports (CSV, metadata JSON, Level-5 `.mat`, PDF).
- **React frontend:** the doc 11 areas (LIVE, TRENDS, CYCLES, RAW, EVENTS,
  HAPTICS, REFERENCES, SESSIONS, EXPORT), a device drawer, calibration and
  mounting-check flows. Stack choices: DEC-011.
- Raw data is canonical; the UI only receives downsampled or summarised data.

## Data flow

```text
foot DRDY ISR ──► acquisition: read foot + shank, µs timestamp, frame index
                     │  raw chip-frame counts (DEC-007)
                     ▼
processing: mount map → calibration → segment orientation from each game rotation
            vector (`ead/feed`, DEC-021) → relative orientation
            → gait state machine + events (shank swing, DEC-022) → ZUPT (foot)
            → cycle features
            → reference comparison → error score, class, confidence
            → haptic engine (EVALUATION, switch on) → motor guard → PWM (DEC-023)
                     │
                     ▼
durable message ring (RAW_SAMPLE_BATCH / EVENT_BATCH / STEP_BATCH, sequence numbers)
      │                                 │
      ▼                                 ▼
Wi-Fi AP WebSocket                  USB COBS frames
192.168.4.1:8080/ws                 /dev/ttyACM*
      └───────────────┬─────────────────┘
                      ▼
dashboard backend: decode → SQLite (raw, summaries, cycles, events)
                      ├─► 20 Hz live channel → React views
                      └─► export package (CSV, metadata.json, session.mat, report.pdf)
```

Commands flow the other way: SESSION_START (with kind, segment limits and locked
reference), SESSION_STOP, PAUSE, RESUME, CONFIG_GET/SET and BACKFILL_REQUEST.
They take effect between frames, and the ACK reports the effective frame index.

## Interfaces

| Interface | Detail |
|---|---|
| SPI (DEC-016) | 1 MHz; SCK 7, MISO 8, MOSI 9; CS foot 43, shank 44; shared RST 41 and WAKE 3 |
| GPIO interrupts | Foot INT → GPIO39, shank INT → GPIO40 (DEC-016). The MPU6500 build used I²C at 400 kHz with INT on GPIO7/8 |
| Motor GPIOs | 1, 2, 42, 4, 5, 6 (DEC-016): service-test pulses and feedback cues (DEC-023) |
| Wi-Fi | Device AP, `ws://192.168.4.1:8080/ws`, binary frames (doc 08 header) |
| USB | Native USB Serial/JTAG `303a:1001`: flashing, and the same binary protocol framed `00 \| COBS(msg ‖ CRC32) \| 00` |
| Protocol payloads | `docs/protocol.md` |
| Dashboard IPC | Tauri commands; live data over `ipc::Channel`; RAW ranges as binary responses |

## Dependencies

| Component | Dependency | Why |
|---|---|---|
| Firmware | PlatformIO 6.2.0, `espressif32 @ 7.1.3` (Arduino-ESP32 2.0.17, ESP-IDF 4.4) | DEC-001 |
| Firmware | No external libraries | IMU driver is register-level; WebSocket via ESP-IDF `esp_http_server` (DEC-010) |
| Dashboard | Tauri 2.11, React 18, TypeScript 5, Vite 8 | Doc 11 |
| Dashboard | rusqlite, tokio-tungstenite, serialport, uPlot, krilla | DEC-011; each added in the milestone that first uses it |
| Verification | Python 3 with pyserial, numpy, scipy | Independent protocol decoder, reference maths, `.mat` reader |

## Constraints

- Right leg only. No bilateral symmetry claim: the metric is the unilateral cycle
  symmetry proxy. No knee/hip angle, ground reaction force or plantar pressure claims.
- No magnetometer and no absolute yaw claim.
- Raw timestamps are preserved end to end. Every feature, event and error traces
  to raw frames and a cycle ID.
- Loss of Wi-Fi never stops device processing.
- Default partition table leaves 1.5 MB for on-device data; the storage
  milestone (M7) needs its own decision before implementation.

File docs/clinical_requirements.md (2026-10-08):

# Clinical requirements — coverage and traceability

Source: the researcher's four additions to the original quotation ("Critical Clinical
Insights", kept locally). The contract package folded these into
`ead_agent_docs_v2/SOURCE_REQUIREMENTS.md`; this file maps each one to the
specification that defines it, the code that implements it, and the test that shows
it.

**Status (2026-10-08):** all four are implemented on the BNO086 build and have run
worn, on battery over Wi-Fi, through the full reference → check → evaluation workflow
(TEST-066–068, TEST-071).

"One number per step" is, as built, one number per **right-leg gait cycle** (right
contact to right contact, about two steps), matching the right-leg scope of V1.

| # | Requirement | Specified in | Implemented | Verified |
|---|---|---|---|---|
| 1 | ZUPT drift correction so speed and distance stay trustworthy for a whole session | doc 05 §6–§8 | Yes | TEST-030: 6.39 m on a 6.00 m course; 200 Hz worn walks with 0 frames lost (TEST-058) |
| 2 | One deviation number per step, driving vibration strength, with a hard safety limit | doc 06 §1–§5 | Yes, per right-leg cycle; graded cues 60–100 % (DEC-026) | TEST-031, TEST-060, TEST-069; deliberate-error walks cued in the matching direction (TEST-071) |
| 3 | Compare each patient to their own baseline from a calibration walk, saved between sessions | doc 12 §2–§3, §6 | Device builds it, dashboard versions and locks it | TEST-031, store tests; patient 67's v6 baseline used in TEST-071 |
| 4 | Export full raw accelerometer, gyroscope and orientation at native rate, timestamped per sample | doc 09 §6, doc 10 | Yes: every 200 Hz frame with its timestamp; both accelerometers also at their native 250 Hz, each sample timestamped (DEC-021) | TEST-018, TEST-022, TEST-029, TEST-035–037 |

## 1. Drift correction (ZUPT)

**Asked for:** "every time the foot is flat on the ground for a moment, the system
resets itself… without this, I won't trust the walking-speed and distance numbers by
the end of a session."

**Specified:** foot-only zero-velocity detector (|‖a‖ − 1 g| ≤ 0.15 g, gyro ≤ 25 °/s,
held 60 ms, in stance), applied as an error-state Kalman update on the velocity
substate rather than a hard reset (doc 05 §6–§7). Speed is reported per cycle with a
quality figure, and flagged as not measured rather than estimated when ZUPT quality is
low (doc 05 §8).

**Built:** the detector, the zero-velocity windows and the distance estimate, measured
against a 6 m course: 6.39 m (TEST-030). Every foot-flat resets the velocity, so drift
cannot build up across a session; cadence comes from cycle timing and does not drift.
Strides outside walking range (over 2.5 m or 2.5 m/s) are not scored.

Thresholds are named constants, overridable at run time, so they can be adapted per
patient (doc 05 §3).

**Foundation:** a gap-free sample stream with real device timestamps. The 30-minute run
(TEST-018) kept all 180,250 frames. Integration uses the per-frame timestamps, not a
nominal period.

## 2. One error number per step

**Asked for:** "one simple number per step that tells me how far off that step was from
normal… the buzz actually gets stronger the more off the step was, with a limit so it
never gets too strong to be unsafe."

**Specified:** exactly one `error_score` in [0,1] per gait cycle, a weighted sum of
seven robust per-feature deviations (doc 06 §2–§3); an independent confidence score
(§5); duty clamped, 5 s maximum continuous on-time and 50 % duty over any 10 s
(§10–§12).

**Built:** the score, the six classes and the five confidence subscores in
`ead_core/error_engine.cpp`, tested against hand-computed cases (TEST-031). Doc 06's
four open values are chosen and justified in DEC-013.

The vibration (DEC-023, DEC-025, DEC-026): one 500 ms cue per scored cycle in an
evaluation, strength `153 + 102·score^1.5·confidence` of 255 (60–100 %), capped at the
motor rail's maximum, held to the 5 s and 50 % limits. The cue sits on the side of the
calf that names the error. An episode ends at the first step under 0.35. Cues pause on
a sensor fault and after 5 s without the laptop (DEC-027).

TEST-071 (2026-10-07): inversion, eversion, plantarflexion and fast walking were cued
in the matching direction.

## 3. Patient-specific baseline

**Asked for:** "a short calibration walk at the start of each session that sets that
patient's own baseline and saves it for next time… not a standard healthy-population
gait pattern."

**Specified:** a reference capture of at least 30 valid cycles with feedback off,
stored as a versioned, immutable profile per patient; each later session runs a
10-cycle check against it; the profile is locked during evaluation so a session can
never change the baseline (doc 12 §2–§3, §6).

**Built:** the whole path. The device collects valid cycles during a REFERENCE_CAPTURE
session and builds a profile from at least thirty; the dashboard assigns a per-patient
version, stores the profile exactly as the device sent it, and locks it once used. The
lock is enforced by the database itself (a trigger), so no code path can edit a used
reference. Profiles persist in the patient's record between sessions.

The profile is computed on the device and versioned by the dashboard (DEC-012), so the
median/MAD statistics have one implementation.

A baseline belongs to the strapping it was recorded in; a new one is recorded after
re-strapping.

## 4. Raw data export

**Asked for:** "full IMU output (accelerometer, gyroscope, orientation) at the native
sampling rate, with a synchronized timestamp on every sample… so we can later check
the device's accuracy against a reference system."

**Capture:** every frame carries a device timestamp and an index; both sensors are read
in the same frame; samples are stored exactly as the device sent them, in native
counts, with the mount maps and scale factors alongside (DEC-007). Frames lost in
transit are re-requested from the device's own buffer (about 4.5 min), and any
remaining gap is counted and shown. Evidence: 180,250 of 180,250 frames over 30
minutes (TEST-018); a dashboard session stored with zero missing (TEST-022).

**Export:** the whole doc 10 package: `raw.csv` (accelerometer, gyroscope and
rotation vector per sensor per frame, timestamped), `accel_native.csv` (both
accelerometers at their native rate, every sample timestamped), `gait.csv`,
`events.csv`, `haptics.csv`, `metadata.json`, `session.mat` and `report.pdf`, each
with the patient's name (DEC-028). Evidence: TEST-035 (the package matches the
database row for row), TEST-036 (`scipy.io.loadmat` agrees with the CSV), TEST-037
(every report section present).

The shank's gyroscope and rotation vector are aligned to the foot-clocked frames.
Timestamps are on the device clock, ready for alignment with an external
reference system in analysis.

## What the dashboard checks

- both sensors present, configured and streaming;
- acceleration magnitude at rest (about 1 g), the fastest check of scaling and mounting;
- dropped frames, bus errors, repeated samples, missing messages, corrupted link frames;
- per-frame flags including saturation on any axis;
- the device's configuration, verified against the hash it reports, recorded with every
  session;
- per-cycle distance with ZUPT quality, the error score, class and confidence, the
  reference workflow, and the export package (sections 1–4).

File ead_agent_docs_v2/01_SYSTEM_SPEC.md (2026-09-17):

# 01 — System Specification

## 1. Product definition
EAD V1 is a right-leg, barefoot, wearable error-augmentation system for gait monitoring/retraining after stroke. It estimates gait-state and movement features from two MPU6050 IMUs and applies spatially directional vibrotactile feedback through six ERM motors. The device itself makes the haptic decision; the desktop application is for observation, configuration, storage, analysis and export.

## 2. Physical configuration
### Foot module
- Location: dorsum/top of the right foot, approximately the midfoot region.
- Mounting: rigid, flat, repeatable.
- Orientation: X forward toward toes; Y medial/left; Z upward away from the ground.
- I²C address: `0x68`.

### Shank module
- Location: anterior/anteromedial right lower shank, on/near the tibial shaft, approximately 10–15 cm below the knee.
- Mounting: rigid, flat, repeatable.
- Same axis orientation as the foot IMU.
- I²C address: `0x69`.

### Haptic band
- Circumferential band around the lower shank.
- Six ERMs equally distributed around the circumference at 60° increments.
- Haptics are intentionally separated from the IMU boards to reduce motion/vibration contamination.

## 3. What V1 directly measures/estimates
- Raw acceleration and angular velocity from both IMUs.
- Relative and segment orientation features.
- Heel-strike/initial-contact estimate.
- Toe-off estimate.
- Foot-flat/zero-velocity intervals.
- Stance and swing durations.
- Right-leg gait cycle time.
- Cadence estimate.
- ZUPT-corrected velocity/step-length/distance estimates where confidence is sufficient.
- Foot dorsiflexion/plantarflexion-related deviation.
- Foot inversion/eversion-related deviation.
- Timing deviation.
- Overall cycle deviation.
- Within-right-leg cycle-repeatability metric, explicitly labelled as a **unilateral symmetry proxy**, not bilateral left-vs-right symmetry.

## 4. Explicit non-claims
V1 MUST NOT claim direct measurement of:
- true knee joint angle;
- true hip joint angle;
- bilateral left/right step symmetry;
- ground-reaction force;
- plantar pressure.

The original project description includes knee-angle estimation, but with only foot + shank sensors this is not a directly observable quantity; a third thigh IMU would be required. fileciteturn9file1L88-L92

## 5. Real-time loop
```text
100 Hz acquisition
  -> calibration
  -> filtering
  -> orientation estimation
  -> gait state/event detector
  -> ZUPT/state correction
  -> step/cycle finalization
  -> feature extraction
  -> reference comparison
  -> error score + confidence
  -> haptic controller
  -> storage + wireless telemetry
```
The haptic controller must not wait for Wi-Fi or the desktop application.

## 6. Reference principle
Every evaluation session uses a versioned, patient-specific reference gait. No generic healthy-population reference is used by default. The reference remains locked during evaluation unless the researcher explicitly starts a new reference-capture workflow.

## 7. Research data principle
Raw data is canonical. Every processed feature, gait event, error and haptic command must be traceable to raw timestamps and step/cycle IDs.

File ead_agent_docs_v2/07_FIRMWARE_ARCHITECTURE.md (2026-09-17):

# 07 — Firmware Architecture

## 1. Runtime components
```text
hardware/
  mpu6050
  pwm_haptics
  gpio
  timer

sensor/
  acquisition
  calibration
  filtering
  orientation

gait/
  state_machine
  events
  zupt
  metrics

reference/
  profile
  builder
  loader

error/
  score
  confidence
  classifer
  hysteresis

storage/
  littlefs
  block_writer
  recovery
  session_manager

protocol/
  websocket
  codec
  commands

safety/
  sensor_watchdog
  haptic_limits

app_state/
  device_state
```

## 2. Timing model
Use a deterministic 100 Hz acquisition timer as the timing backbone.
- Sensor interrupt indicates data ready.
- Acquisition task reads both sensors in a synchronized frame as closely as practical.
- Every frame receives one master ESP32 monotonic timestamp and one frame sequence number.
- Long operations are queued outside the acquisition path.

## 3. Processing priority
Highest priority:
1. sensor acquisition;
2. safety/fault checks;
3. gait/orientation update;
4. haptic control;
5. storage block flushing;
6. Wi-Fi/network telemetry.

Wi-Fi or storage must never block acquisition or haptic control.

## 4. Sensor abstraction
Define a common `ImuSample` interface:
```text
sensor_id
imu_timestamp_us
ax ay az
 gx gy gz
quaternion
calibration_state
health_flags
```
The current concrete implementation is MPU6050. A future BNO086 backend can produce the same interface without changing gait/error algorithms.

## 5. No battery logic
Do not add battery ADC code, percentage estimators, charger-state parsing, fuel-gauge code, or switch-status handling.

## 6. Device states
```text
BOOT
SELF_TEST
CALIBRATING
REFERENCE_CAPTURE
READY
RUNNING
PAUSED
FAULT
RECOVERY
```
Motor outputs are OFF in all states except `RUNNING` when haptic conditions are valid.

## 7. Motor service/test mode
The desktop app may request a service test only when the device is not in a patient evaluation session.
- one motor at a time by default;
- all-six test sequence allowed only in service mode;
- hard safety limits still apply;
- test events are marked as `SERVICE_TEST` and excluded from gait/haptic outcome statistics.

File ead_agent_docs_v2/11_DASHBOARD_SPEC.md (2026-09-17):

# 11 — Desktop Dashboard Specification

## 1. Technology
- Tauri 2.
- React.
- TypeScript.
- Rust backend.
- Desktop targets: Windows and Linux.

## 2. Main areas
### LIVE
Show:
- patient name/ID;
- selected reference profile;
- session/segment;
- elapsed time;
- current cycle ID;
- cadence;
- speed;
- stance/swing;
- unilateral symmetry proxy;
- foot/shank orientation;
- error score;
- confidence;
- current error class;
- ZUPT state/quality;
- sensor status;
- Wi-Fi status;
- motor state.

### TRENDS
Exactly seven primary trend panels:
1. Cadence
2. Unilateral cycle symmetry proxy
3. Error score
4. Stance/swing
5. Foot angle
6. Haptic response
7. ZUPT quality

### STEP/CYCLE TABLE
Columns:
- cycle ID;
- start/end;
- cycle time;
- stance;
- swing;
- speed;
- error score;
- confidence;
- error class;
- haptic channels/level.

### RAW DATA
Filters:
- Foot/Shank;
- time range;
- cycle;
- signal;
- error markers.

Display full raw accel/gyro plus calculated orientation/status. Clicking an error marker must jump to the corresponding raw timestamp range.

### EVENTS
Timeline of initial contact, toe-off, foot-flat, ZUPT, cycle boundaries, errors, haptic ON/OFF, faults.

### HAPTICS
Table and timeline for motor channels, PWM, duration, error class, error score and confidence.

### REFERENCE PROFILES
Create/view/select/reference version history. A reference is immutable once used for an evaluation session.

### SESSIONS
Hierarchy:
```text
Patient
  -> Session
      -> Segment 001
      -> Segment 002
```

### EXPORT
Buttons/actions:
- CSV package;
- MATLAB `.mat`;
- PDF report.

## 3. Rendering rule
Do not render charts at raw 100 Hz sample granularity. The backend keeps all data; the UI receives downsampled/aggregated visual data (target 20 Hz live display) while the raw store remains untouched.

## 4. Configuration
Researcher-configurable:
- segmentation step limit;
- segmentation error limit;
- calibration/reference workflow controls;
- analysis threshold/gain parameters explicitly exposed by the firmware;
- report/export options.

Safety-critical maxima are read-only from the dashboard during a running session.

## 5. Device states
Dashboard must visibly distinguish:
- disconnected;
- booting;
- calibrating;
- reference capture;
- ready;
- running;
- paused;
- fault;
- recovered session.

## 6. Motor test
Service/test UI is disabled when a patient session is RUNNING.

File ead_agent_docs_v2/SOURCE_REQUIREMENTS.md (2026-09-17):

# Source Requirements Captured in This Handoff

This handoff was rebuilt from the project specification and the later clinical-insight requirements supplied in the conversation.

## Original project requirements
- Wearable IMU gait system.
- Dual IMU placement on shank + foot.
- 6-channel vibrotactile feedback.
- 100 Hz sensor data target.
- Wi-Fi/BLE wireless concept; V1 selects Wi-Fi.
- Desktop Windows/Linux dashboard.
- Gait speed, cadence, step symmetry.
- Stance/swing.
- Foot-drop-like detection.
- Original requirement says knee-angle estimation; V1 explicitly excludes direct knee-angle measurement because the final hardware has only foot + shank sensing.
- Heel-strike/toe-off events.
- Real-time plots.
- Clinical/research PDF report.
- CSV/MATLAB export. fileciteturn9file1L69-L96

## Later clinical requirements
- Distinguish real movement errors from noisy/off sensors.
- Keep gait numbers accurate over a session.
- Use ZUPT during foot-flat/zero velocity intervals.
- One quantitative error value per gait cycle/step drives haptic strength.
- More deviation -> stronger vibration, with a hard upper limit.
- Compare each patient to their own normal/reference gait.
- Short reference capture and persistent stored baseline.
- Export full raw accelerometer/gyro/orientation with a synchronized timestamp on every sample. fileciteturn9file0L9-L49 fileciteturn9file0L51-L59

## Final hardware decisions supplied later
- V1 sensors are MPU6050 ×2.
- Foot sensor address 0x68.
- Shank sensor address 0x69.
- Existing breakout-board I²C pull-ups are used.
- No FSR.
- Direct PWM through six MOSFETs.
- Two HT7833 haptic rails, three motors each; firmware does not implement power-management logic.
- No battery ADC.
- No switch status.
- Internal ESP32 flash for recovery storage.

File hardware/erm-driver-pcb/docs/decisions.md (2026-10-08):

# Engineering Decisions

Handoff decisions locked in `EAS_ERM_Driver_PCB_Handoff/08_DECISION_LOG.md` are not repeated here. This file records decisions made during the KiCad implementation.

## DEC-001 — Use the invoice's 100 nF capacitors as per-channel local decoupling

**Date:** 2026-09-22  **Status:** Accepted (user decision)

### Context
Invoice #3698208 contains only 17× 100 nF 1206 MLCC, which the handoff BOM does not use. Single-layer routing forces each channel's rail and GND to arrive from opposite sides of the board (see DEC-003). Without a local capacitor, the MOSFET/diode switching current loop closes through the regulator output capacitors, which are far away.

### Options Considered
1. One 100 nF from rail to GND at each channel (6 parts).
2. Option 1 plus 100 nF at each HT7833 VIN/VOUT (10 parts).
3. Swap the motor suppression capacitors C9–C14 from 10 nF to 100 nF.
4. Leave the 100 nF capacitors off this board.

### Decision
Option 1: C15–C20 = 100 nF, each from the channel's rail to GND, placed next to that channel's diode and MOSFET.

### Reason
It shrinks each channel's high-di/dt loop (diode → rail → capacitor → GND → MOSFET source) to a local loop. Option 3 would raise the charge pulled through the MOSFET at each PWM turn-on about 10× (C·V = 330 nC vs 33 nC).

### Trade-offs
6 extra parts and a little area. The handoff circuit is otherwise unchanged; C9–C14 stay 10 nF.

## DEC-002 — 220 µF polymer footprint: `Capacitor_SMD:CP_Elec_5x5.9`

**Date:** 2026-09-22  **Status:** Accepted

### Context
The handoff describes the part as "220 µF 6.3 V polymer, D5×L6.1" and requires the land pattern to be verified. The user confirmed it is an SMD V-chip (can on a plastic base with flat terminals).

### Decision
Use KiCad `CP_Elec_5x5.9`. Every `CP_Elec_5x5.x` footprint has identical pads (3.0×1.6 mm at ±2.2 mm); only the height/3D model differs, and 5.9 mm is the closest listed height to 6.1 mm.

### Consequences
A paper fit check (lay the part on the unmirrored 1:1 print) comes before etching.

## DEC-003 — PWM and M- wire pads are enclosed by copper, not on the board edge

**Date:** 2026-09-22  **Status:** Accepted (user decision)

### Context
Planarity analysis: with one copper layer, no jumpers and no traces under component bodies, the channels of a rail group cannot have their PWM or M- pads on the outer board edge (K3,3).

### Options Considered
1. Pads set just inside a GND/rail trace (wires soldered on top, passing over that trace).
2. Edge pads plus 0 Ω jumpers.
3. Edge pads plus traces routed between the pads of 1206 parts.

### Decision
Option 1.

### Trade-offs
Wires cross over a bare copper trace to leave the board (insulated wire; tie down or glue for strain relief). No jumpers, and no bridging risk from traces under parts on an unmasked board.

## DEC-004 — 0 Ω jumpers: target zero, allowed if necessary

**Date:** 2026-09-22  **Status:** Accepted (user instruction)

A 0 Ω 1206 jumper (or wire link) is permitted only if routing cannot close without one, or it clearly reduces board area or a switching loop. Each jumper must be recorded here. Neither invoice includes 0 Ω parts.

## DEC-005 — Etch rules 0.4 mm; hand-solder footprint variants

**Date:** 2026-09-22  **Status:** Accepted (user decision)

- Minimum track width 0.4 mm and minimum clearance 0.4 mm (laser-toner transfer).
- Footprints:
  - Resistors: `R_1206_3216Metric_Pad1.30x1.75mm_HandSolder`
  - Capacitors: `C_1206_3216Metric_Pad1.33x1.80mm_HandSolder`
  - Regulators: `SOT-89-3_Handsoldering` (superseded for U1/U2 by the local ≥ 0.4 mm variant, DEC-010)
  - MOSFETs: `SOT-23_Handsoldering`
  - Diodes: `D_SOD-123`. KiCad has no hand-solder SOD-123 variant, and inventing one would need verification against the vendor drawing, so the stock footprint is kept.
- Handoff trace-width minimums still apply: SW/GND trunks ≥ 1.5 mm, rails ≥ 1.0 mm, motor branches ≥ 0.8 mm, PWM/gate 0.4–0.5 mm.

## DEC-006 — No copper labels; printed assembly drawing instead

**Date:** 2026-09-22  **Status:** Accepted (user decision)

No text in copper. Pad functions and reference designators appear on the F.Fab layer and are plotted as an assembly drawing (1:1 and 3:1).

## DEC-007 — Motor pads: the handoff's 8-pad map, long A+/B+ pads

**Date:** 2026-09-22  **Status:** Accepted (user confirmed 6 motors and the handoff pad map)

Motor pads: `A+`, `M1-`, `M2-`, `M3-`, `B+`, `M4-`, `M5-`, `M6-`. The A+ and B+ pads are 2.5 × 7.0 mm so they can take up to three wires; the other M- pads are 2.5 × 2.5 mm.

## DEC-008 — Generate schematic and PCB from one Python data model

**Date:** 2026-09-22  **Status:** Accepted

### Context
The agent cannot operate the KiCad GUI. KiCad 10 provides `kicad-cli` (ERC, DRC with schematic parity, exports) and the `pcbnew` Python module. There is no Python API for schematics.

### Decision
`EAS_ERM_Driver/scripts/build.py` holds the part list and pin→net map once.
- It writes the `.kicad_sch` as S-expressions (library symbols copied from the installed KiCad libraries).
- It builds the `.kicad_pcb` through `pcbnew` from the same data (footprints, nets, symbol paths, placement, tracks, zones).
- `kicad-cli pcb drc --schematic-parity` then independently checks that the two agree.

### Consequences
The layout is reproducible and parametric: column pitch and row offsets are constants. Hand edits in the KiCad GUI are overwritten if `build.py` is re-run, so to keep them, stop using `build.py` for layout after editing.

## DEC-009 — HT7833 pinout: Holtek 1 GND, 2 VIN (tab), 3 VOUT

**Date:** 2026-09-22  **Status:** Accepted (user confirmed genuine Holtek parts)

Confirmed against Holtek HT78xx Rev. 1.51. The SOT-89 tab is pin 2 (VIN). The regulator's heat-spreading copper is therefore `SWITCHED_SYSTEM+` copper, connected solidly (no thermal relief).

## DEC-010 — Project-local SOT-89 land with ≥ 0.4 mm pad gaps

**Date:** 2026-09-22  **Status:** Accepted

### Context
KiCad's stock SOT-89 lands, `SOT-89-3` and `SOT-89-3_Handsoldering`, leave only **0.254 mm** between pin 1 (GND) or pin 3 (VOUT) and the inner corner of the wide tab pad (pin 2, VIN). That breaks the 0.4 mm etch rule (DEC-005). On a toner-transfer board such a gap can bridge under the regulator body, shorting VIN to GND or VOUT where it cannot be inspected after soldering.

### Options Considered
1. Keep the stock land and add a DRC exception for it.
2. Trim the wide part of the tab pad so every gap is ≥ 0.4 mm.

### Decision
Option 2. `EAS.pretty/SOT-89-3_Handsoldering_0.4mm` is generated by `build.py` from the stock hand-solder land:
- The wide tab strip now starts at x = −0.85 mm instead of −1.125 mm.
- A 0.9 mm neck joins it to the pin-2 lead.
- Pin positions, pin-1/3 pads and the tab end at x = +3.0 are unchanged.

### Trade-offs
0.275 mm less tab land under the body, next to the pin row. The tab still extends 1.75 mm beyond the body.

### Verification
- DRC is clean at 0.4 mm.
- The pin pitch (1.50 mm) and package outline (A 4.40–4.70, E 3.94–4.40 mm) were checked against Holtek HT78xx Rev 1.51, page 9.
- Fit against the physical part: checked by the paper fit check.

## DEC-011 — No GND pour under part bodies

**Date:** 2026-09-22  **Status:** Accepted

### Context
The first fill put 0.3–0.8 mm pour slivers between the pads of every 1206/SOD-123 part. It also produced 7 "connection too narrow" warnings (0.31–0.38 mm necks).

### Decision
`build.py` adds a copper-pour keepout rule area over the courtyard of every part except U1/U2 (whose tab copper is the heat spreader) and the wire pads. Every GND pad is connected by an explicit track, so no connection depends on the pour. Zone settings:
- clearance 0.5 mm
- minimum width 0.5 mm
- thermal spokes 0.5 mm
- islands removed

### Trade-offs
Less GND copper area (321 mm² pour remains). In exchange there is no hidden copper under parts on an unmasked board, and no narrow slivers to lift during etching.

## DEC-012 — 0.6 mm clearance around wire pads

**Date:** 2026-09-22  **Status:** Accepted

Wire pads carry a local 0.6 mm clearance instead of the global 0.4 mm. A hand-soldered wire needs more margin to neighbouring copper than a component lead, and the board has no solder mask. It costs about 0.2 mm per pocket.

## DEC-013 — Floorplan: one row of six channel cells ("comb")

**Date:** 2026-09-22  **Status:** Accepted

### Context
The user asked for the smallest area with no shape limit. Constraints:
- Single-layer planarity.
- The SOT-89 is placed on the top side only, so its pin order around the part is fixed (clockwise VIN → VOUT → GND).
- The same holds for each channel cell (clockwise PWM → M- → rail → GND).

### Decision
One row: `[U1 block][ch1 ch2 ch3][U2 block][ch4 ch5 ch6]`.
- **Top edge:** SWITCHED_SYSTEM+ line (1.5 mm) to both regulators.
- **Buses:** 3.3 V rail bus (1.0 mm) under the SW line; GND bus (1.5 mm) along the bottom edge.
- **Cells:** each hangs D, the 10 nF and the 100 nF from the rail bus. Its GND "tooth" (1.0 mm) runs on its right side to the bus.
- **Wire pads:** M- pad on the left of each cell; PWM pad at the bottom, enclosed by the GND bus.
- **Regulator orientation:** U1 has its tab facing the SW strip on the left edge; U2 has its tab up to the SW line.
- **Power corner:** bottom-left, holding SWITCHED_SYSTEM+, GND, ESP_SW_BAT+ and ESP GND.
- **MOTOR_B+:** sits on the free top edge above channels 4–6. MOTOR_A+ is a vertical pad beside U1's output.

### Reason
- Both regulators must sit at the left end of their group, so the VOUT rail flows away from the SW input without crossing GND.
- The SW line must reach U2 across the left group, so it runs along the rail side (top).
- A two-row version needs a second GND bus and a second SW run for roughly the same area, so it was not built.

### Result
- 82.75 × 19.0 mm (1572 mm²) with 0 jumpers.
- Channel pitch 9.45 mm, which is 0.05 mm above the clearance-limited minimum (tooth to next M- pad at 0.6 mm).

## DEC-014 — Schematic uses global labels on every pin

**Date:** 2026-09-22  **Status:** Accepted

- Local labels on the root sheet produce net names prefixed with "/" (e.g. `/PWM1`). Global labels give the exact handoff names (`PWM1`, `SWITCHED_SYSTEM+`), which the PCB nets must match for the schematic-parity DRC.
- `build.py` draws a 2.54 mm stub plus a global label at each pin rather than routing schematic wires. It is less pretty but trivially correct to generate.
- `M1+`…`M6+` are not separate nets; they are `HAPTIC_3V3_A/B`, because a net carries one name.

## DEC-015 — Assembly drawing content

**Date:** 2026-09-22  **Status:** Accepted

- **Part labels:** F.Fab only. Each part body shows its reference and a short value (`C15`/`100n`); all 1206 capacitors look identical in hand.
- **Wire pads:** short labels `PWR+`, `GND`, `ESP+`, `EGND`, `PWM1`…`PWM6`, `A+`, `B+`, `M1-`…`M6-`, plus a legend below the outline.
- **Value field:** C7/C8 carry Value `220uF`; the "6.3 V polymer, SMD V-chip D5" text is in Description, which the BOM exports.

## DEC-016 — Compact two-row variant (both sides < 50 mm), original kept unchanged

**Date:** 2026-09-22  **Status:** Accepted (user request)

### Context
The user asked to shorten the 82.75 × 19.0 mm strip, accepting more width, with both sides under 50 mm. The existing design must stay untouched: copy it, then edit the copy.

### Options Considered
1. **Two stacked rows of three channels, same orientation, each with its regulator at the left end.**
2. **A shared middle GND bus with row B rotated 180°**, so all PWM pads sit along the middle. Rejected: the rotated regulator block needs a SWITCHED_SYSTEM+ line across the board and a crossing-free path round the shared bus, for about the same size.
3. **Three rows of two channels.** Rejected: about 38 × 49 mm, a larger area.

### Decision
Option 1, in `EAS_ERM_Driver_compact/` (project `EAS_ERM_Driver_compact`). It is a full copy of `EAS_ERM_Driver/` with only the PCB layout section of `build.py` changed.
- **What changed (layout only):**
  - Row A = U1 block + ch1–3 on rail A; row B = U2 block + ch4–6 on rail B.
  - Every cell and regulator block is the verified single-row geometry, shifted.
  - Both HT7833 tabs face the SWITCHED_SYSTEM+ strip on the left edge, so the old top-edge SW line is gone.
  - GND bus A (between the rows) joins GND bus B down the right edge with a 1.5 mm link beside the end of the rail B bus.
  - MOTOR_B+ becomes a vertical 2.5 × 7 pad next to U2, mirroring MOTOR_A+.
- **What is unchanged:** netlist, parts, footprints, rules, schematic content.

### Result
- 44.70 × 32.60 mm (1457 mm²), **0 jumpers**, 0 vias, 0 holes.
- The single-row original: 82.75 × 19.00 mm (1572 mm²), also 0 jumpers.

### Trade-offs
- PWM1–3 and M1–3- are now in the middle of the board (row A), and PWM4–6 and M4–6- in row B. Wires reach the row A pads over bare copper, as before.
- Row A's motor return current flows along GND bus A, down the right-edge link and along GND bus B to the power pad. That is about 95 mm of 1.5 mm copper, roughly 30 mΩ by calculation. At 0.36 A (three motors starting) the drop is about 11 mV. Estimated, not measured.

## DEC-017 — Mini variant: four rule relaxations approved by the user

**Date:** 2026-09-22  **Status:** Accepted (user request and user-approved relaxations)

### Context
The user asked whether the compact board (44.70 × 32.60 mm) could be made smaller, without changing it: copy it, then edit the copy. My analysis found that under the existing rules the compact layout is close to its limit.
- The six channel cells are about 95 % packed (parts plus required clearances fill the 9.45 × 15.1 mm cell).
- Each regulator block is set by the 8 × 5.9 mm courtyard of the 220 µF next to the two input caps.
- The best rearrangement I found was worth about 0–3 %.
- A 0 Ω jumper would only remove the right-edge GND link, which costs 0.5 mm.

### Options offered (estimates given before building)
1. Wire-pad clearance 0.6 → 0.4 mm (the user's etch rule; undoes DEC-012).
2. Copper-to-edge 1.0 → 0.5 mm (handoff 04 §10 "prefers" 1 mm).
3. SWITCHED_SYSTEM+ strip and GND buses 1.5 → 1.0 mm (handoff 04 §2 recommends 1.5 mm).
4. Standard KiCad SOT-23 / SOT-89 / 1206 lands instead of hand-solder ones (undoes DEC-005's footprint choice).

### Decision
The user approved all four. `EAS_ERM_Driver_mini/` is a copy of `EAS_ERM_Driver_compact/`. Its `build.py` was changed as follows:
- **Footprints:** `R_1206_3216Metric`, `C_1206_3216Metric`, `SOT-23`, and `EAS:SOT-89-3_0.4mm`. The last is derived from the standard `SOT-89-3`, which has the same 0.25 mm tab-corner gap, so it gets the DEC-010 fix: the wide tab starts at x = −0.85, with a 0.9 mm neck.
- **Rules:** `WIRE_CLR` 0.4, `EDGE` 0.5, power trunks 1.0. `check.py` now requires trunks ≥ 1.0 mm.
- **Cell re-derived for the smaller lands:** pitch 8.1 mm (was 9.45), row height 13.94 mm (was 15.1). The GND tooth is 0.8 mm, the handoff's motor-branch minimum.
- **Regulator block re-derived:** about 13.4 mm wide (was ~15.3). The power corner is J1 (PWR+), J3 (ESP+), J2 (GND), J4 (EGND) along the bottom-left; ESP+ sits between PWR+ and GND and is fed from PWR+.

### Result
- 38.91 × 29.28 mm (1139 mm², 22 % smaller than the compact, 28 % smaller than the single row), **0 jumpers**.
- ERC, DRC and parity clean, and `check.py` passes, all on the first build (TEST-010).

### Trade-offs
- **Harder hand soldering:** shorter pads.
- **Cutting:** only 0.5 mm of copper margin, so cut carefully along the line.
- **Narrower power copper:** 1.0 mm still carries over 2 A, against about 1 A needed. This is a calculation, not a measurement.
- **Less regulator heat-spreading copper:** 20.1 mm² per regulator (compact 28.3 mm²), plus the 1.0 mm SW strip. Regulator temperature is recorded in the rail test.

## DEC-018 — Tight variant: 0.3 mm gaps and tight courtyards

**Date:** 2026-09-22  **Status:** Accepted (user choice)

### Context
The user asked whether the mini (38.91 × 29.28 mm) could go smaller. I offered four options:
- Stay with the mini.
- Tighter packing with 0.3 mm gaps (estimated about 37 × 27 mm).
- 0805 R/C, which means buying new parts (about 35 × 24 mm).
- Both (about 33 × 22 mm).

The user chose tighter packing with 0.3 mm gaps.

### Decision
`EAS_ERM_Driver_tight/` is a copy of the mini. Its `build.py` was changed as follows:
- **Clearance 0.3 mm** everywhere: the global rule, net classes and wire pads. Track widths are unchanged (signals 0.5, motor 0.8, rails 1.0, trunks 1.0), as is the 0.5 mm edge margin.
- **Tight courtyards instead of disabling the courtyard check.** Project copies of each footprint (`EAS:R_1206_tight`, `C_1206_tight`, `SOT-23_tight`, `D_SOD-123_tight`, `CP_Elec_5x5.9_tight`, `SOT-89-3_0.4mm_tight`) get one courtyard rectangle equal to the body and pad extents + 0.1 mm; KiCad's own add about 0.25–0.3 mm. KiCad's courtyard-overlap DRC stays active, so parts can never touch or overlap; they just sit closer.
- **Pads unchanged:** the SOT-89 keeps its ≥ 0.4 mm pad-gap fix.
- **Cell re-derived:** pitch 7.45 mm (was 8.1), row height 13.15 mm (was 13.94).
- **Regulator block re-derived:** about 12.8 mm wide (was ~13.4).

### Result
- 36.07 × 27.60 mm (996 mm²): 12.6 % smaller than the mini, 37 % smaller than the single row.
- **0 jumpers.** ERC, DRC and parity clean; `check.py` passes (TEST-011).

### Trade-offs
- **Etching:** 0.3 mm gaps are below the 0.4 mm the user's toner process was set for, so the transfer must be crisp. Inspect every gap before soldering.
- **Soldering:** parts sit about 0.2 mm apart body to body, which is harder to solder and rework.
- **Copper:** GND pour 144 mm² (mini 193); regulator heat-spreader copper 19.9 mm² each (mini 20.1).

## DEC-019 — Fabricate the tight variant, accepting 0.3 mm gaps on 0.5 mm-rated paper

**Date:** 2026-09-23  **Status:** Accepted (user decision)

### Context
The user will etch this themselves with Robocraze A4 PCB toner transfer paper (pack of 10), on a laser printer of unknown dpi (most home lasers are 600 dpi). The product listing claims "almost lossless transfer for upto 0.5mm tracks" and gives no gap figure.

Measured against that claim:
- **Traces:** the narrowest trace in every variant is 0.5 mm, exactly at the claim.
- **Gaps:** single row / compact / mini use 0.4 mm; the tight variant uses 0.3 mm, below it.
- **Pour-to-copper gap:** 0.5 mm in every variant.

### Options offered
1. Test strip first (trace/gap pairs 0.25–0.6 mm plus the real pad patterns).
2. A 0.5 mm-gap variant, estimated about 39.2 × 29.6 mm, only ~0.3 mm per side larger than the mini.
3. Keep the tight variant (36.07 × 27.60 mm) and accept the risk.
4. 0805 parts for a smaller board (needs a new purchase).

### Decision
Option 3: fabricate the tight variant as built. No further variants.

### Consequences
- The 0.3 mm gaps are below the paper's stated capability, so **the risk is a short between neighbouring tracks** where the copper between them does not clear.
- Mitigation is inspection, not design: see the pre-etch and post-etch checks in `hardware.md`.
- If the etch shows bridges that cannot be cleaned up, the fallback is the mini (0.4 mm gaps, 38.91 × 29.28 mm), which is already built and verified.

### Parts check
All parts are in stock with spares, and no 0 Ω part is needed: HT7833 2/10, IRLML6344 6/10, 1N5819W 6/22, 100 Ω 6/40, 100 kΩ 6/20, 1 µF 4/10, 10 µF 2/20, 10 nF 6/20, 100 nF 6/17, 220 µF 2/8.

## DEC-020 — Six-up toner sheet with a printed ruler

**Date:** 2026-09-23

**Status:** Accepted

### Context
The tight variant is what will be etched. A toner transfer usually takes more than one attempt, and the transfer is worthless if the printer silently rescales the page: at 96 % scale the 0.3 mm gaps and every land shrink with it, and nothing on a single-board print reveals it.

### Options Considered
1. Print the existing single-board toner PDF several times.
2. Tile copies on one sheet with a printed dimension reference.
3. Rely on measuring the board outline alone to detect rescaling.

### Decision
Option 2: `EAS_ERM_Driver_tight/scripts/panel.py` generates a 3 × 2 sheet from the verified board, 30 mm apart, with a 100 mm horizontal ruler (10 mm ticks) and a 50 mm vertical ruler outside the copies.

### Reason
- Six copies from one sheet of transfer paper; a smeared transfer costs one copy, not a sheet.
- A 100 mm reference resolves a 1 % scale error as 1 mm, which a ruler shows plainly. The board outline is only 36 mm, where the same error is 0.36 mm and easy to miss.
- Two rulers, because a printer can scale the axes differently.

### Trade-offs
- The sheet must be cut twice: the ruler strip off first, then the copies apart. The 30 mm pitch is not kerf allowance: it leaves about 15 mm of paper around each cut-out copy, which the user folds around the copper clad to hold the transfer in place under the iron. It was 8 mm until the user asked for the fold-over margin, and the gap is now an argument (`panel.py 3 2 30`).
- `panel.py` is a separate script, not part of `export.sh`: it reads the verified board and writes only to `output/`, so it can never alter a verified design.

### Consequences
- The panel PDF is a derived artifact. After any change to the tight board, re-run `panel.py`; it re-measures its own output and exits non-zero if the scale check fails.
- The same script works for the other variants by changing `PROJ`, and takes the grid as arguments (`panel.py 3 2`).

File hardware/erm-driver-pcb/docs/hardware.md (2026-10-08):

# Hardware

## Bill of materials (populated)
Generated BOM: `EAS_ERM_Driver/output/EAS_ERM_Driver_bom.csv` (identical in the compact variant; the mini has the same parts and values with the standard lands `R_1206_3216Metric`, `C_1206_3216Metric`, `SOT-23`, `EAS:SOT-89-3_0.4mm`, per DEC-017). Stock figures come from handoff `06_BOM.md` / `09_SOURCE_NOTES.md` (Robu order of 13/09/2026) and invoice #3698208 (16/09/2026).

| Ref | Part | Qty | Footprint | Stock |
|---|---|---:|---|---:|
| U1, U2 | Holtek HT7833, 3.3 V 500 mA LDO, SOT-89 | 2 | `EAS:SOT-89-3_Handsoldering_0.4mm` (DEC-010) | ~10 (user) |
| Q1–Q6 | Infineon IRLML6344, N-MOSFET | 6 | `SOT-23_Handsoldering` | 10 |
| D1–D6 | 1N5819W Schottky 40 V (KEXIN) | 6 | `D_SOD-123` | 22 |
| R1–R6 | 100 Ω 1206, gate series | 6 | `R_1206_…_HandSolder` | 40 |
| R7–R12 | 100 kΩ 1206, gate pulldown | 6 | `R_1206_…_HandSolder` | 20 |
| C1, C2, C5, C6 | 1 µF 1206 50 V, regulator in/out | 4 | `C_1206_…_HandSolder` | 10 |
| C3, C4 | 10 µF 1206, regulator input bulk | 2 | `C_1206_…_HandSolder` | 20 |
| C7, C8 | 220 µF 6.3 V polymer, SMD V-chip D5 | 2 | `CP_Elec_5x5.9` (DEC-002) | 8 |
| C9–C14 | 10 nF 1206, across each motor | 6 | `C_1206_…_HandSolder` | 20 |
| C15–C20 | **100 nF 1206**, rail-to-GND per channel (DEC-001) | 6 | `C_1206_…_HandSolder` | 17 (invoice #3698208) |
| J1–J18 | SMD wire solder pads (copper only, no part) | 18 | `EAS:WirePad_*` | — |

No 0 Ω jumper is used.

## Pinouts used (manufacturer pin → footprint pad)
| Part | Pad 1 | Pad 2 | Pad 3 | Source |
|---|---|---|---|---|
| HT7833 SOT-89 | GND | VIN (also the tab) | VOUT | Holtek HT78xx Rev 1.51, pin description (confirmed) |
| IRLML6344 SOT-23 | Gate | Source | Drain | Infineon datasheet (handoff 09) |
| 1N5819W SOD-123 | Cathode (band) | Anode | — | KiCad `D_SOD-123`: pad 1 = K. **Check the delivered part's band before soldering.** |
| 220 µF polymer | + | − | — | KiCad `CP_Elec`: pad 1 = + (marked "+" on the assembly drawing) |

## Wire pads
See `README.md` for the pad map.
- **Sizes** meet or exceed handoff 03: power 3.0 × 2.5, motor 2.5 × 2.5, ESP 2.0 × 2.0 mm. A+ and B+ are 2.5 × 7.0 mm for up to three wires.
- **Construction:** every pad is SMD (F.Cu + F.Mask opening), has no hole, and carries a 0.6 mm local clearance (DEC-012).

## Electrical
| Net / class | Track width | Notes |
|---|---|---|
| SWITCHED_SYSTEM+ trunk | 1.5 mm | left-edge strip and top-edge line |
| GND bus | 1.5 mm | bottom edge; per-channel teeth 1.0 mm |
| HAPTIC_3V3_A / _B | 1.0 mm | rail buses and every rail stub |
| M1-…M6- | 0.8 mm | |
| PWM / GATE | 0.5 mm | |

- **Clearances:**
  - 0.4 mm minimum (`.kicad_pro`).
  - Pour to other nets 0.5 mm.
  - Wire pads 0.6 mm.
  - Copper to board edge 1.0 mm (single row and compact); 0.5 mm in the mini and tight variants (DEC-017).
- **DRC custom rules (`EAS_ERM_Driver.kicad_dru`):**
  - No vias, no holes, nothing on B.Cu.
  - Power, rail and motor tracks ≥ 0.8 mm.
  - Signal tracks 0.4–0.5 mm.
- **Switching loop per channel:** the local 100 nF sits between the rail bus directly above the diode and the channel's GND tooth. The high-di/dt loop (D → rail → C15..C20 → GND tooth → Q source → Q drain → D) is therefore about 2.4 × 5 mm ≈ 12 mm². This is an estimate from the layout coordinates and has not been measured.

## Thermal (regulators)
- **Load (handoff 04):** 3 motors × 90 mA = 270 mA per regulator, which dissipates 0.243 W at 4.2 V in; 360 mA start current (transient) dissipates 0.324 W.
- **Datasheet rise:** with θJA = 200 °C/W (Holtek, "no ambient airflow, no heat sink"), the junction rise would be 49 °C and 65 °C (transient).
- **Heat-spreading copper:** the tab (VIN) is solidly connected to SWITCHED_SYSTEM+ copper.
  - Single row: a zone of 38.5 mm² at U1 and 20.9 mm² at U2, plus the 1.5 mm SW line joined to both tabs.
  - Compact: 28.3 mm² and 28.4 mm², plus the 1.5 mm left-edge SW strip joined to both tabs.
  - Mini: 20.1 mm² each; tight: 19.9 mm² each. Both have the 1.0 mm left-edge SW strip. These have the least copper, so check the temperature first on them.
- This copper is there to lower θJA; the three-motor rail test (handoff 07 §6) records the regulator temperature.

## Fabrication (toner transfer)
**Paper:** Robocraze A4 PCB toner transfer paper, laser printers only, iron or laminator. Its listing claims "almost lossless transfer for upto 0.5mm tracks" and states no gap figure. Every variant's narrowest **trace** is 0.5 mm, at that claim. The **gaps** are 0.4 mm (single row, compact, mini) and 0.3 mm (tight, DEC-019). The tight variant is therefore being etched below the paper's stated capability, deliberately.

**Extra checks when etching the tight variant (DEC-019):**
1. Print with toner saving OFF and density at maximum; the darkest possible toner is what survives the transfer.
2. Before ironing, inspect the printout under a loupe or phone macro: every gap must be a clean white line, with no toner bridging.
3. After transfer and before etching, inspect again and repair any bridged gap by scraping the toner with a scalpel.
4. After etching, inspect every gap, especially around the SOT-23 pins, the SOT-89 pins and between the rail buses and the GND pour. Clear any remaining copper with a scalpel.
5. Before soldering, measure resistance: SWITCHED_SYSTEM+ to GND, each rail to GND, and HAPTIC_3V3_A to HAPTIC_3V3_B. All must be open circuits.
6. If bridges cannot be cleaned up, fall back to the mini variant (0.4 mm gaps), which is built and verified.

1. Print at **100 % scale** on a laser printer, with "fit to page" / "scale to fit" disabled. Both PDFs are already mirrored for face-down transfer.
   - Tight variant: `EAS_ERM_Driver_tight/output/EAS_ERM_Driver_tight_TONER_PANEL_6up_MIRRORED_print_1to1.pdf` — six copies per A4 sheet, 30 mm apart, with a printed ruler (DEC-020), so one smeared transfer costs a copy rather than the sheet. The 30 mm pitch leaves about 15 mm of paper on each side of a cut-out copy, to fold around the copper clad while ironing. Other grids: `python3 scripts/panel.py <cols> <rows> [gap mm]`, which verifies its own output at 1:1.
   - Mini variant (the 0.4 mm-gap fallback): the same sheet at `EAS_ERM_Driver_mini/output/EAS_ERM_Driver_mini_TONER_PANEL_6up_MIRRORED_print_1to1.pdf`.
   - Any variant, one copy: `output/*_TONER_F.Cu_MIRRORED_print_1to1.pdf`.
2. **Check the print scale before ironing.** On either panel sheet, measure the horizontal ruler from tick 0 to tick 100: it must read exactly 100.0 mm centre to centre, and the vertical ruler 50.0 mm. If either is off, the printer rescaled the page; fix the print dialog and reprint. Then measure a board outline: **36.07 × 27.60 mm** (tight), **82.75 × 19.0 mm** (single row), **44.70 × 32.60 mm** (compact) or **38.91 × 29.28 mm** (mini). The PDFs were measured at those sizes in software (TEST-005, TEST-009, TEST-010, TEST-012).
   Cut the ruler strip off the sheet before ironing, then cut the copies apart through the middle of the 30 mm gaps so each keeps its paper border.
3. Before ironing, lay the real parts on the unmirrored fit-check print (TEST-007). Check especially the 220 µF V-chip base, the SOT-89 and the SOD-123 band orientation.
4. Transfer, etch, and clean the toner off. No drilling is required.
5. Cut along the outline line (hacksaw or shear). Copper stays 1 mm inside the line on the single row and compact, and 0.5 mm on the mini and tight, so on those two cut on the line or slightly outside it, and never more than 0.3 mm inside.
6. Inspect under magnification for bridges. Look first at the SOT-23 pins, the SOT-89 pins and every gap between the rail buses and the GND pour. Then measure resistance: SWITCHED_SYSTEM+ to GND, each rail to GND, and HAPTIC_3V3_A to HAPTIC_3V3_B (handoff 07 §1–2).

## Assembly
Place parts from `output/*_placement_3to1.pdf` (3× enlarged). Every part body shows its reference and value, e.g. `C15`/`100n`, because the 1206 capacitors are unmarked. Keep `output/*_assembly_3to1.pdf` beside it when a pin number is needed (U1, U2, Q1–Q6): it is the same drawing with the pads and pin numbers sketched, at the cost of the digits overlapping some labels.
1. **1206 parts first (R1–R12, C1–C6, C9–C20).** Keep the values separate: 1 µF (C1, C2, C5, C6), 10 µF (C3, C4), 10 nF (C9–C14), 100 nF (C15–C20).
2. **D1–D6.** Cathode band toward the top rail bus (pad 1 at the top).
3. **Q1–Q6.** Drain (single pin) faces left, toward the M- pad.
4. **U1, U2.** Pre-heat: the tab joins a solid VIN copper area with no thermal relief. U1's tab faces the left edge; U2's tab faces the top edge (single row) or the left edge (compact).
5. **C7, C8 (220 µF).** "+" pad as marked, on the right: toward A+ (C7), and toward the rail B riser (single row) or B+ (compact) for C8.
6. **Tight variant:** parts sit about 0.2 mm apart and gaps are 0.3 mm. Inspect the etched board for bridges before soldering, solder one part at a time, and re-check neighbours after each joint.
7. **Mini and tight variants:** the standard lands are shorter. Use a fine tip and thin solder, and check each joint for bridges under magnification.
8. **Wires last.** Tin each pad, solder the wire, then glue or tie the wire down. Insulate any wire that crosses bare copper.

## Bench test wiring (XIAO ESP32-S3)
The handoff leaves the GPIO numbers to firmware (`08_DECISION_LOG.md`), so this mapping is a
recommendation, not a spec. It matches `firmware/erm_channel_test/erm_channel_test.ino`.

| Board pad | XIAO pad | GPIO | Note |
|---|---|---|---|
| PWM1 | D0 | 1 | |
| PWM2 | D1 | 2 | |
| PWM3 | D2 | 3 | strapping pin (JTAG source select); safe here, the only DC load is the 100 k gate pulldown |
| PWM4 | D3 | 4 | |
| PWM5 | D4 | 5 | |
| PWM6 | D5 | 6 | |
| GND or EGND | GND | — | **mandatory**: the logic reference |
| ESP+ | BAT+ | — | final battery build only; leave open while the XIAO is on USB |
| PWR+ | — | — | current-limited supply at 3.7–4.0 V, or the switched battery |

D6/D7 (GPIO43/44) are the UART pins and are avoided. 20 kHz PWM, 8-bit duty.

**Firmware and dashboard.** `firmware/erm_channel_test/erm_channel_test.ino` takes one command per
line at 115200: `<ch> <percent>` to set a channel, `1`-`6` to ramp one for the bring-up test, `a`
for all six, `0` for all off, `k` as a silent keepalive, `?` to print both the commanded duty and
`ledcRead()` of every pin (they can disagree; the second is what drives a motor).

**Failsafe.** The firmware switches every channel off after 3 s without a command, provided anything
is driving. LEDC holds its last duty with no CPU involvement, so without this a dropped USB link
leaves a motor running until the battery is flat. The dashboard sends `k` once a second, so an open
window keeps motors alive and a closed or crashed one stops them. **A dashboard without the
keepalive will see motors stop after 3 s** - run the current `erm_dashboard.py`. `firmware/dashboard/erm_dashboard.py` is a
tkinter window with one slider per motor that drives the same protocol
(`python3 erm_dashboard.py [port] [--offline] [--selftest]`). The XIAO re-enumerates on every
reset and usually returns on a different `/dev/ttyACM` number, so the no-argument form with the
port dropdown is the practical one. While the link is down the status line turns red and says
NOT CONNECTED: a channel holds its last duty until a new command actually reaches the board.

**Backfeed warning:** with ESP+ connected and the XIAO's USB plugged in, the XIAO's own charger
can push current into `SWITCHED_SYSTEM+` (`README.md`, observation, unverified). During bench
testing, power the board from the supply and the XIAO from USB, joined only at ground.

## Known hardware limitations
- **Bare copper:** no solder mask. Consider conformal coating or Kapton tape after bring-up.
- **Operating window:** the HT7833 regulates down to a cell voltage of about 3.3 V + dropout (360 mV typ at 500 mA per datasheet; less at 270 mA) (handoff 07 §8).
- **Outside this board (observation, unverified):** the XIAO ESP32-S3 has its own charger on its BAT pads. With the XIAO's USB plugged in and the master switch ON, it may push charge current into SWITCHED_SYSTEM+. Check against the XIAO schematic; this PCB is unaffected.

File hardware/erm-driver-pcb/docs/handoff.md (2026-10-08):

# Project Handoff

## Project
EAS V1 six-channel ERM haptic driver PCB (KiCad 10), built from `EAS_ERM_Driver_PCB_Handoff/`.

## Current Objective
Fabricate the V1 board by toner transfer, assemble it, and bring it up per handoff `07_VALIDATION_AND_TEST.md`.

## Variants
Four layouts of the same circuit, all with 0 jumpers and all verified in software:
- `EAS_ERM_Driver/`: single row, 82.75 × 19.0 mm.
- `EAS_ERM_Driver_compact/`: two rows, 44.70 × 32.60 mm (DEC-016).
- `EAS_ERM_Driver_mini/`: two rows with relaxed rules and standard lands, 38.91 × 29.28 mm (DEC-017).
- `EAS_ERM_Driver_tight/`: the mini with 0.3 mm gaps and tight courtyards, 36.07 × 27.60 mm (DEC-018).

The user chooses which to fabricate. Everything below applies to both unless stated.

## Current State
- **What works (verified in software):**
  - Complete schematic and single-layer PCB; ERC 0, DRC 0, 0 unconnected, schematic parity 0.
  - `check.py` passes every handoff verification item.
  - 82.75 × 19.0 mm; 0 vias, 0 holes, 0 jumpers.
  - Gerbers, a 1:1 mirrored toner PDF, assembly drawings and the BOM are in `EAS_ERM_Driver/output/`.
- **Built:** the tight variant drives the six motors on the device.

## Architecture
SWITCHED_SYSTEM+ feeds two HT7833 LDOs. Each makes its own 3.3 V rail for three low-side IRLML6344 channels (flyback diode, 10 nF across the motor, 100 nF local decoupling). Everything is wired off-board through 18 SMD pads. Details: `architecture.md`.

## Important Files
- `EAS_ERM_Driver/scripts/build.py`: **source of truth** (netlist model, schematic generator, layout).
- `EAS_ERM_Driver_compact/`: compact variant; same structure, its own `scripts/build.py` (layout section differs).
- `EAS_ERM_Driver_mini/`: mini variant; its own `scripts/build.py` (footprints, rules and layout differ; DEC-017).
- `EAS_ERM_Driver_tight/`: **the variant being fabricated** (DEC-019); its own `scripts/build.py`, plus `scripts/panel.py`, which tiles the verified board into the six-up toner sheet with its ruler (DEC-020) and verifies its own PDF.
- `EAS_ERM_Driver/scripts/check.py`: verification asserts and connection summary.
- `EAS_ERM_Driver/scripts/export.sh`: rebuild, verify and export everything.
- `EAS_ERM_Driver/EAS_ERM_Driver.kicad_{pro,sch,pcb,dru}`: generated KiCad project.
- `EAS_ERM_Driver/EAS.pretty/`, `EAS.kicad_sym`: generated project libraries.
- `EAS_ERM_Driver/output/`: deliverables and reports.
- `docs/`: this documentation.

## Completed Work
- Planning with user Q&A: DEC-001…DEC-009.
- Datasheet check: no ESR requirement.
- Generator, layout, verification and export pipeline; DEC-010…DEC-015.

## Current Work
None in progress. The tight variant is built and drives the six motors on the device.

## Approaches Replaced
- **Grouped wire pads on the board edge with zero jumpers:** impossible (K3,3). Don't retry without accepting jumpers.
- **Stock KiCad SOT-89 land:** 0.254 mm internal gap violates the 0.4 mm rule (DEC-010).
- **GND pour under parts:** slivers and hidden bridge risk (DEC-011).
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

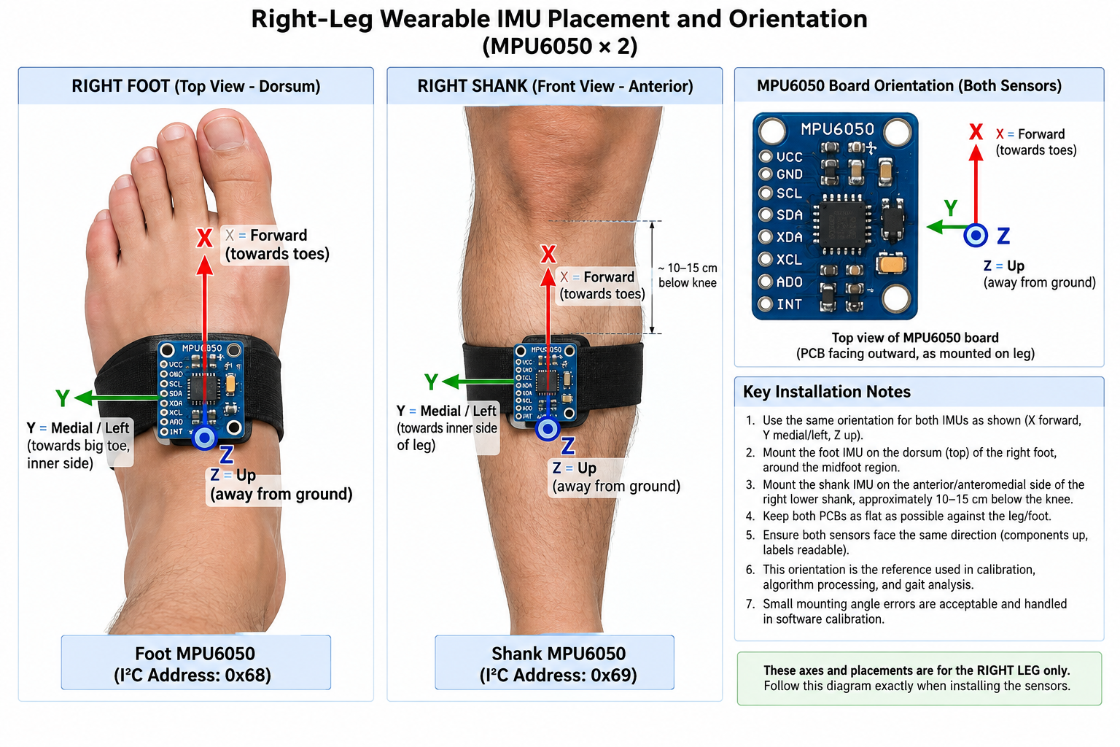
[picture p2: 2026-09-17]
ead_agent_docs_v2/reference_images/RIGHT_LEG_IMU_PLACEMENT.png

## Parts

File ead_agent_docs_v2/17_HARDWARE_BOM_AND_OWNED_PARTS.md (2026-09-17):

# 17 — V1 Hardware BOM / Owned Parts

## Required active hardware
| Item | V1 quantity | Notes |
|---|---:|---|
| Seeed XIAO ESP32-S3 | 1 | Main controller; 2nd board remains spare |
| MPU6050 breakout | 2 | Foot + shank |
| ERM coin vibration motor | 6 | One per haptic channel; user has 12, 6 remain spare |
| IRLML6344 SOT-23 N-MOSFET | 6 | One per motor; user has 10 |
| 1N5819W SOD-123 Schottky | 6 | One per motor; user has 22 |
| 100 Ω 1206 resistor | 6 | One gate resistor/channel; user has 40 |
| 100 kΩ 1206 resistor | 6 | One gate pulldown/channel; user has 20 |
| 100 nF 1206 capacitor | 2 minimum | One at each MPU; more may be used for local decoupling |
| 10 nF 1206 capacitor | 0 default | DNP motor suppression footprint; optional after EMI test |
| 10 µF 1206 capacitor | 2+ | General local rail decoupling/spares |
| 1 µF 1206 capacitor | 4 minimum | HT7833 input/output, 2 per regulator |
| 220 µF polymer | 2 | One per haptic rail; user has 8 |
| HT7833 | 2 | One regulator per 3-motor group |
| 1S 3.7 V ~2000 mAh battery | 1 | Physical power source; firmware has no battery monitoring |
| MCP73833 charger module | 1 | Hardware-side charging; firmware does not control it |

## Wiring material
- Thin flexible wire from existing JST-SH harnesses may be cut free and soldered directly to the PCB.
- Main battery conductors should use heavier flexible wire than motor/signal conductors.
- No motor connectors or XIAO headers are part of the final PCB design.

## Parts intentionally NOT used in V1
- BNO055.
- BNO086.
- DRV2605L.
- TCA9548A.
- FSRs.
- AMS1117-3.3.
- USB boost/charger module.
- Battery fuel gauge.
- Battery ADC.
- Switch-status input.

The user's latest Robu order confirms IRLML6344, 1N5819W, 100 Ω/100 kΩ 1206 resistors, capacitors, two XIAO ESP32-S3 boards, 220 µF polymer capacitors, 1 µF capacitors and the copper-clad PCB. fileciteturn8file0L36-L65 fileciteturn8file7L502-L525
The Robocraze cart contains two XIAO boards, 12 coin motors and three BNO086s; only the two XIAOs/6 motors required for V1 are active in this specification, with BNO086 reserved for future hardware. fileciteturn8file4L338-L346

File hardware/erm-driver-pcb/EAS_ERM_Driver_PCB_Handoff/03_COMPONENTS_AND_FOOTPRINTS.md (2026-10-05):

# Components, Footprints, and Assembly

## Purchased/available design parts
The user's Robu invoice confirms the following stock relevant to this board: 10× IRLML6344, 22× 1N5819W, 40× 100 ohm 1206 resistors, 20× 100 kOhm 1206 resistors, 20× 10 uF 1206 capacitors, 20× 10 nF 1206 capacitors, 8× 220 uF 6.3 V polymer capacitors, 10× 1 uF 50 V 1206 capacitors, plus the single-sided 20×30 cm 1.5 mm copper-clad board. The same invoice also confirms the XIAO ESP32-S3 stock, but the module is separate from this PCB. 

## Components to populate on this PCB
| Ref | Value / Part | Qty | Footprint target | Notes |
|---|---|---:|---|---|
| U1,U2 | HT7833 3.3 V SOT-89 | 2 | `Package_TO_SOT_SMD:SOT-89-3` or verified manufacturer-compatible custom footprint | Pin 1 GND, 2 VIN, 3 VOUT |
| Q1-Q6 | IRLML6344 | 6 | `Package_TO_SOT_SMD:SOT-23` | G=1, S=2, D=3 |
| D1-D6 | 1N5819W | 6 | `Diode_SMD:D_SOD-123` | Cathode to motor+, anode to drain |
| R1-R6 | 100 ohm | 6 | `Resistor_SMD:R_1206_3216Metric` | Gate series |
| R7-R12 | 100 kOhm | 6 | `Resistor_SMD:R_1206_3216Metric` | Gate pulldown |
| C1,C2 | 1 uF | 2 | `Capacitor_SMD:C_1206_3216Metric` | Mandatory regulator input |
| C3,C4 | 10 uF | 2 | `Capacitor_SMD:C_1206_3216Metric` | Input bulk |
| C5,C6 | 1 uF | 2 | `Capacitor_SMD:C_1206_3216Metric` | Mandatory regulator output |
| C7,C8 | 220 uF polymer | 2 | Exact verified pad/land pattern for purchased D5xL6.1 part | Output bulk |
| C9-C14 | 10 nF | 6 | `Capacitor_SMD:C_1206_3216Metric` | EMI suppression directly across motor |

## External solder pads
Create project-local SMD solder-pad footprints. They are not connectors.

Recommended starting sizes:
- Power input pads: >= 3.0 mm x 2.5 mm copper.
- Motor pads: >= 2.5 mm x 2.5 mm copper.
- ESP32 interface pads: >= 2.0 mm x 2.0 mm copper.

The agent may increase pad size when needed for mechanical strength or hand soldering, but should not shrink below these targets without a documented reason.

No holes are permitted in these pads.

## Component orientation
Orient SOT-89, SOT-23, SOD-123, 1206 capacitors and resistors so that the board remains easy to hand solder and inspection is straightforward. Exact orientation is free for the optimizer.

## Marking
Silkscreen is optional for toner-transfer fabrication but, if a silkscreen-equivalent layer is plotted, use very short labels:
- `PWR`, `GND`
- `PWM1` ... `PWM6`
- `A+`, `B+`
- `M1-` ... `M6-`
- `U1`, `U2`, `Q1` ... `Q6`

On an etch-only board, prefer copper legends or simple etched labels if desired. Avoid wasting area on long text.

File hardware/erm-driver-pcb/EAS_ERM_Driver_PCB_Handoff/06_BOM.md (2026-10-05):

# Final V1 BOM — 6-Channel ERM Driver PCB

| Ref | Part | Qty populated | User stock | Notes |
|---|---|---:|---:|---|
| U1,U2 | Holtek HT7833, 3.3 V, SOT-89 | 2 | ~10 available | Two independent rails |
| Q1-Q6 | Infineon IRLML6344, SOT-23 | 6 | 10 | Low-side motor switches |
| D1-D6 | 1N5819W, SOD-123 Schottky | 6 | 22 | Flyback, one per motor |
| R1-R6 | 100 ohm, 1206 | 6 | 40 | Gate series resistors |
| R7-R12 | 100 kOhm, 1206 | 6 | 20 | Gate pulldowns |
| C1,C2 | 1 uF, 1206, X7R | 2 | 10 | HT7833 input minimum |
| C3,C4 | 10 uF, 1206, X7R | 2 | 20 | Input bulk |
| C5,C6 | 1 uF, 1206, X7R | 2 | 10 | HT7833 output minimum |
| C7,C8 | 220 uF, 6.3 V polymer | 2 | 8 | Output bulk, polarity required |
| C9-C14 | 10 nF, 1206, X7R | 6 | 20 | Motor EMI suppression |
| — | SMD solder pads | 18? | Custom | 2 power + 8 ESP32 + 8 motor = 18 total pad sites |

## External connections
### Power input
2 pads:
- `SWITCHED_SYSTEM+`
- `GND`

### ESP32 interface
8 pads:
- `ESP_SW_BAT+`
- `GND`
- `PWM1` ... `PWM6`

### Motor interface
8 pads:
- `MOTOR_A+`
- `M1-`
- `M2-`
- `M3-`
- `MOTOR_B+`
- `M4-`
- `M5-`
- `M6-`

There are **18 external wire pad sites** because the ESP32 ground and power input are intentionally separate physical interfaces. The internal nets are common as specified.

## Not populated / not on board
- Charger components.
- Battery protection components.
- Switch.
- ESP32.
- IMUs.
- FSRs.
- 0 ohm jumper, unless routing proves one is absolutely necessary.

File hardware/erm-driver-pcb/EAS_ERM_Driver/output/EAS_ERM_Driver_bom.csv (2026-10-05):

Refs | Value | Footprint | Description | Qty
C1,C2,C5,C6 | 1uF | Capacitor_SMD:C_1206_3216Metric_Pad1.33x1.80mm_HandSolder | U1 input, X7R 50 V,U1 output, X7R 50 V,U2 input, X7R 50 V,U2 output, X7R 50 V | 4
C3,C4 | 10uF | Capacitor_SMD:C_1206_3216Metric_Pad1.33x1.80mm_HandSolder | U1 input bulk, X7R,U2 input bulk, X7R | 2
C7,C8 | 220uF | Capacitor_SMD:CP_Elec_5x5.9 | Rail A bulk, 6.3 V polymer, SMD V-chip D5,Rail B bulk, 6.3 V polymer, SMD V-chip D5 | 2
C9-C14 | 10nF | Capacitor_SMD:C_1206_3216Metric_Pad1.33x1.80mm_HandSolder | Motor 1 suppression, across motor,Motor 2 suppression, across motor,Motor 3 suppression, across motor,Motor 4 suppression, across motor,Motor 5 suppression, across motor,Motor 6 suppression, across motor | 6
C15-C20 | 100nF | Capacitor_SMD:C_1206_3216Metric_Pad1.33x1.80mm_HandSolder | Channel 1 local rail decoupling (DEC-001),Channel 2 local rail decoupling (DEC-001),Channel 3 local rail decoupling (DEC-001),Channel 4 local rail decoupling (DEC-001),Channel 5 local rail decoupling (DEC-001),Channel 6 local rail decoupling (DEC-001) | 6
D1-D6 | 1N5819W | Diode_SMD:D_SOD-123 | Flyback, motor 1,Flyback, motor 2,Flyback, motor 3,Flyback, motor 4,Flyback, motor 5,Flyback, motor 6 | 6
J1 | SWITCHED_SYSTEM+ | EAS:WirePad_3.0x2.5mm | SMD wire solder pad (no hole) | 1
J2 | GND | EAS:WirePad_3.0x2.5mm | SMD wire solder pad (no hole) | 1
J3 | ESP_SW_BAT+ | EAS:WirePad_2.0x2.0mm | SMD wire solder pad (no hole) | 1
J4 | ESP_GND | EAS:WirePad_2.0x2.0mm | SMD wire solder pad (no hole) | 1
J5 | PWM1 | EAS:WirePad_2.0x2.0mm | SMD wire solder pad (no hole) | 1
J6 | PWM2 | EAS:WirePad_2.0x2.0mm | SMD wire solder pad (no hole) | 1
J7 | PWM3 | EAS:WirePad_2.0x2.0mm | SMD wire solder pad (no hole) | 1
J8 | PWM4 | EAS:WirePad_2.0x2.0mm | SMD wire solder pad (no hole) | 1
J9 | PWM5 | EAS:WirePad_2.0x2.0mm | SMD wire solder pad (no hole) | 1
J10 | PWM6 | EAS:WirePad_2.0x2.0mm | SMD wire solder pad (no hole) | 1
J11 | MOTOR_A+ | EAS:WirePad_2.5x7.0mm | SMD wire solder pad (no hole) | 1
J12 | M1- | EAS:WirePad_2.5x2.5mm | SMD wire solder pad (no hole) | 1
J13 | M2- | EAS:WirePad_2.5x2.5mm | SMD wire solder pad (no hole) | 1
J14 | M3- | EAS:WirePad_2.5x2.5mm | SMD wire solder pad (no hole) | 1
J15 | MOTOR_B+ | EAS:WirePad_2.5x7.0mm | SMD wire solder pad (no hole) | 1
J16 | M4- | EAS:WirePad_2.5x2.5mm | SMD wire solder pad (no hole) | 1
J17 | M5- | EAS:WirePad_2.5x2.5mm | SMD wire solder pad (no hole) | 1
J18 | M6- | EAS:WirePad_2.5x2.5mm | SMD wire solder pad (no hole) | 1
Q1-Q6 | IRLML6344 | Package_TO_SOT_SMD:SOT-23_Handsoldering | Low-side switch, motor 1,Low-side switch, motor 2,Low-side switch, motor 3,Low-side switch, motor 4,Low-side switch, motor 5,Low-side switch, motor 6 | 6
R1-R6 | 100 | Resistor_SMD:R_1206_3216Metric_Pad1.30x1.75mm_HandSolder | Gate series, channel 1,Gate series, channel 2,Gate series, channel 3,Gate series, channel 4,Gate series, channel 5,Gate series, channel 6 | 6
R7-R12 | 100k | Resistor_SMD:R_1206_3216Metric_Pad1.30x1.75mm_HandSolder | Gate pulldown, channel 1,Gate pulldown, channel 2,Gate pulldown, channel 3,Gate pulldown, channel 4,Gate pulldown, channel 5,Gate pulldown, channel 6 | 6
U1,U2 | HT7833 | EAS:SOT-89-3_Handsoldering_0.4mm | 3.3 V LDO, rail A (M1-M3),3.3 V LDO, rail B (M4-M6) | 2

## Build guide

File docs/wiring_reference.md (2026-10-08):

# EAD V1 — Wiring reference

Every electrical connection in the device: the XIAO ESP32-S3, both BNO086
breakouts, the six ERM motor channels, the two haptic power rails, the
harnesses and the power input. Pin assignment fixed by DEC-016.

## 1. How to trust this document

Every connection carries the evidence behind it. Nothing here is an estimate.

| Mark | Meaning |
|---|---|
| **[DS]** | Read from the manufacturer's datasheet (sources in §16) |
| **[MEAS]** | Measured on this project's hardware |
| **[USER]** | Confirmed by the builder looking at the actual part |
| **[CONTRACT]** | Fixed by `ead_agent_docs_v2/` |
| **[DEC]** | A recorded project decision (DEC-nnn) |

Build status (2026-10-07): **the DEC-016 build is the device.** Two BNO086 on SPI,
and the ERM driver PCB, tight variant (`hardware/erm-driver-pcb/`), with everything
fitted (user, 2026-10-02 and 2026-10-05; §15).

## 2. Parts

| Part | Qty | Exact type | Role |
|---|---:|---|---|
| Controller | 1 | Seeed XIAO ESP32-S3 (**plain, not Sense**) | Everything |
| IMU | 2 | 7Semi BNO086 breakout (ES-12143), PS0/PS1 jumpers opened | Foot, shank |
| Motor | 6 | ERM coin vibration motor — rated 3 V, 90 mA (120 mA at start) | Feedback |
| MOSFET | 6 | Infineon IRLML6344, SOT-23 | Low-side switch per motor |
| Diode | 6 | 1N5819W, SOD-123 Schottky | Flyback per motor |
| Resistor | 6 | 100 Ω, 1206 | Gate series |
| Resistor | 6 | 100 kΩ, 1206 | Gate pulldown |
| Regulator | 2 | HT7833, 3.3 V 500 mA LDO — Holtek, SOT-89 | Haptic rails A and B |
| Capacitor | 2 | 220 µF polymer | Bulk, one per haptic rail |
| Capacitor | 4 | 1 µF, 1206 | HT7833 input + output, each regulator |
| Capacitor | 2+ | 100 nF, 1206 | At each sensor's 3V3 pad |
| Capacitor | 1+ | 10 µF, 1206 | Logic 3V3 rail |
| Capacitor | 6 | 10 nF, 1206 | Across each motor (tight BOM C9–C14; fitted, §15) |
| Capacitor | 6 | 100 nF, 1206 | Local rail decoupling per channel (tight BOM C15–C20) |
| Resistor | 2 | 33 Ω, 1206 | SPI series termination, §5 (recommended, not in the contract) |
| Cell | 1 | 1S Li-ion/LiPo, 3.7 V nominal, ~2000 mAh | Power |
| Charger | 1 | MCP73833 module — SmartElex module (`docs/hardware.md`) | Charging |

## 3. XIAO ESP32-S3 — every pin

All 15 usable GPIOs are used. There is no spare. **[DEC-016]** The motors were
rewired on 2026-10-07 to a new order over the same six pins **[USER]** **[DEC-029]**.

| XIAO pin | GPIO | Dir | Connects to | Evidence |
|---|---:|---|---|---|
| D0 | 1 | Out | Motor 6 gate network (§6) | [DEC] no internal pull at reset [DS] |
| D1 | 2 | Out | Motor 5 gate network | [DEC] no internal pull [DS] |
| D2 | 3 | Out | **WAKE** pad on both BNO086 boards | [DEC] strapping pin, see §14 |
| D3 | 4 | Out | Motor 1 gate network | [DEC] no internal pull [DS] |
| D4 | 5 | Out | Motor 4 gate network | [DEC] no internal pull [DS] |
| D5 | 6 | Out | Motor 2 gate network | [DEC] no internal pull [DS] |
| D6 | 43 | Out | **CS** pad, foot BNO086 | [DEC] internal pull-up keeps it deselected through boot [DS] |
| D7 | 44 | Out | **CS** pad, shank BNO086 | [DEC] same [DS] |
| D8 | 7 | Out | **SCK** pad on both boards, via 33 Ω | [DEC] |
| D9 | 8 | In | **MISO** pad on both boards | [DEC] |
| D10 | 9 | Out | **MOSI** pad on both boards, via 33 Ω | [DEC] |
| Back pad MTCK | 39 | In | **INT** pad, foot BNO086 | [DEC] weak pull-up after reset — never a motor [DS] |
| Back pad MTDO | 40 | In | **INT** pad, shank BNO086 | [DEC] |
| Back pad MTDI | 41 | Out | **RST** pad on both boards | [DEC] |
| Back pad MTMS | 42 | Out | Motor 3 gate network | [DEC] no internal pull, no power-up glitch [DS] |
| 3V3 | — | Power out | **3V3** pad on both boards; 700 mA available | [DS] Seeed |
| GND | — | Power | Common ground | — |
| 5V | — | — | **Leave unconnected.** Dead when running from battery | [DS] Seeed |
| BAT+ / BAT− pads (underside) | — | Power in | Battery, §9. **BAT− is the pad nearer the USB port**; confirm against the silkscreen before soldering | [DS] Seeed |
| USB-C | — | — | Programming and the bench link | [MEAS] |

Never connected: GPIO0, 45, 46 (strapping), GPIO19/20 (USB), GPIO26–37 (flash
and octal PSRAM). On the **Sense** variant the four back pads belong to the
camera — this map is for the plain XIAO ESP32-S3 only.

## 4. BNO086 breakout — every pad on each board

Pad names exactly as printed on the 7Semi board. **[DS]** 7Semi ES-12143 §3.

| Pad | Foot board | Shank board | On-board state | Evidence |
|---|---|---|---|---|
| 3V3 | XIAO 3V3 | XIAO 3V3 | Supply, **3.3 V only** (chip max 3.63 V) | [DS] CEVA §6.1 |
| GND | GND | GND | — | — |
| MISO | D9 / GPIO8 | D9 / GPIO8 | Same chip pin as SDA, so it carries the I²C pull-up | [MEAS] TEST-039 |
| SCK | D8 / GPIO7 via 33 Ω | D8 / GPIO7 via 33 Ω | Same chip pin as SCL, pulled up | [MEAS] TEST-039 |
| MOSI | D10 / GPIO9 via 33 Ω | D10 / GPIO9 via 33 Ω | Same chip pin as SA0, pulled up | [MEAS] TEST-039 |
| CS | D6 / GPIO43 | D7 / GPIO44 | No pull-up on the board | [MEAS] TEST-039 |
| WAKE | D2 / GPIO3 | D2 / GPIO3 | Pulled up; **same net as PS0** | [USER] |
| RST | GPIO41 pad | GPIO41 pad | **10 kΩ pull-up on each board** | [USER] |
| INT | GPIO39 pad | GPIO40 pad | Active-low output | [DS] CEVA fig. 1-6 |
| BOOT | open | open | Pulled high (the bench part booted its application firmware, which needs BOOT high at reset) | [MEAS] TEST-040 |
| PS1 | open | open | Pulled up; jumper opened | [USER] [MEAS] |
| PS0 | open | open | Same net as WAKE — drive it through the WAKE pad only | [USER] |
| SCL | open | open | Same net as SCK | [DS] CEVA fig. 1-6 |
| SDA | open | open | Same net as MISO | [DS] CEVA fig. 1-6 |
| Qwiic ×2 | open | open | I²C only; dead in SPI mode | [MEAS] |

Nine pads wired per board: 3V3, GND, MISO, SCK, MOSI, CS, WAKE, RST, INT.

Consequences worth knowing:

- **RST is pulled up twice** — two 10 kΩ in parallel is 5 kΩ. GPIO41 pulls that
  low with 0.66 mA, nothing. The line no longer floats during boot, so the
  open item from the previous revision is closed. **[USER]**
- **SPI mode is latched by the boards themselves.** PS0/WAKE and PS1 are pulled
  high on each board, and CEVA requires exactly that: "Both pins must be high
  from before reset until after the first assertion of H_INTN to select the SPI
  interface." **[DS]** CEVA §1.2.4. The firmware therefore keeps WAKE high from
  reset until the first INT, and never pulses RST while WAKE is low.
- **No firmware update of the BNO086 from the XIAO.** CEVA recommends wiring BOOT
  to a GPIO for that; there is no spare GPIO. A sensor firmware update would need
  temporary wiring.

## 5. SPI bus

| Net | XIAO | Foot BNO086 | Shank BNO086 |
|---|---|---|---|
| SCK | D8 / GPIO7 → 33 Ω | SCK | SCK |
| MOSI | D10 / GPIO9 → 33 Ω | MOSI | MOSI |
| MISO | D9 / GPIO8 | MISO | MISO |
| CS_FOOT | D6 / GPIO43 | CS | — |
| CS_SHANK | D7 / GPIO44 | — | CS |
| INT_FOOT | GPIO39 | INT | — |
| INT_SHANK | GPIO40 | — | INT |
| RST | GPIO41 | RST | RST |
| WAKE | D2 / GPIO3 | WAKE | WAKE |
| 3V3 | 3V3 | 3V3 | 3V3 |
| GND | GND | GND | GND |

Settings: **SPI mode 3**, MSB first, **3 MHz maximum** **[DS]**. Measured working
at 3 MHz on short bench wires **[MEAS]**.

The foot sensor sits at the end of a long cable (§11), which the bench test
did not have. Three measures make that link robust:

1. **33 Ω in series on SCK and MOSI, at the XIAO end.** Damps ringing on the
   long run. With the line's few tens of pF this adds about a nanosecond of
   delay — irrelevant at 3 MHz. Recommended engineering practice, not in the
   contract.
2. **A ground conductor on each side of SCK** in the foot cable (§11).
3. **Run the bus at 1 MHz — and no slower.** Two sensors streaming three
   reports each at 100 Hz need well under 20 kB/s; 1 MHz gives 125 kB/s, over
   six times that. The floor comes from latency, not bandwidth: CEVA asks for
   each interrupt to be serviced "typically within 1/10 of the fastest sensor
   period" **[DS]** CEVA §1.2.4.1 — 1 ms at 100 Hz. If both sensors interrupt
   together, the second waits for the first transfer, about half a millisecond
   at 1 MHz. Move to 3 MHz only after a soak test
   on the real harness shows zero errors. This is a firmware setting.

The two boards' I²C pull-ups on SCK, MISO and MOSI end up in parallel. Every
one of those lines is driven push-pull in SPI mode, so the pull-ups only add a
little static current.

## 6. One motor channel — repeated six times

**As built (2026-10-02):** the six channels and both haptic rails (§7) are on a
separate ERM driver PCB, designed in `hardware/erm-driver-pcb/` (KiCad, with its own
docs). Same circuit as below, plus a 10 nF across each motor (C9–C14, fitted), a
100 nF rail-to-GND per channel, and 10 µF at each regulator input **[PCB project
BOM]**. Its PWM1–PWM6 pads take the motor GPIOs of §3; its `ESP+` pad feeds the
XIAO's BAT+ from the switched battery.

**[CONTRACT]** `02_HARDWARE_WIRING.md` §4. Pin numbers **[DS]** Infineon.

```text
  3V3_HAPTIC_A or _B ---+------------------+
                        |                  |
                        |           cathode (band)
                      ERM +            1N5819W
                        |               anode
                      ERM -                |
                        +------------------+------ pin 3  DRAIN
                                                   IRLML6344
  XIAO GPIO --- 100 R ---------------------+------ pin 1  GATE
                                           |       pin 2  SOURCE ---- GND
                                         100 k
                                           |
                                          GND
```

| Part | Pin | Connects to |
|---|---|---|
| IRLML6344 (SOT-23) | 1, gate | 100 Ω from the GPIO, and 100 kΩ to GND |
| | 2, source | GND |
| | 3, drain | ERM − and the diode's anode |
| 1N5819W (SOD-123) | cathode — the **band** end | The channel's haptic rail (ERM +) |
| | anode | The MOSFET drain (ERM −) |
| ERM motor | + | The channel's haptic rail, A or B |
| | − | The MOSFET drain |

Why it is safe:

- Gate threshold is 0.5–1.1 V; on-resistance at most 37 mΩ at 2.5 V gate
  **[DS]**. The ESP32's 3.3 V drive turns it fully on.
- The 100 kΩ pulldown holds the gate at 0 V from power-up until firmware drives
  the pin. That only works because no motor GPIO has an internal pull-up (§14).
- Diode backwards = a dead short across the rail. **Check every band.**
- The diode sits on the board, across the channel's two wires — not at the motor.
- The 10 nF footprint across each motor stays empty unless EMI testing shows a
  need **[CONTRACT]**.

### All six channels

| Motor | On the band | XIAO pin | GPIO | Rail | Rail wire in the band harness |
|---|---|---|---:|---|---|
| M1 | Anterior, 0° | D3 | 4 | A | +A |
| M2 | Anterolateral, 60° | D5 | 6 | A | +A |
| M3 | Posterolateral, 120° | back pad MTMS | 42 | A | +A |
| M4 | Posterior, 180° | D4 | 5 | B | +B |
| M5 | Posteromedial, 240° | D1 | 2 | B | +B |
| M6 | Anteromedial, 300° | D0 | 1 | B | +B |

XIAO pins as rewired by the user on 2026-10-07 (DEC-029), with M5 and M6 then swapped
at the user's request (M5 D1, M6 D0); until then M1–M6 were on D0, D1, MTMS, D3, D4, D5. The Rail column is the design's (M1–M3 on rail A). Each motor's
position is confirmed by a service pulse felt on the band.

Angles from the front of the shin, clockwise seen from above, right leg
**[CONTRACT]** `06_ERROR_AND_HAPTIC_ENGINE.md` §7. Rail A feeds the front-lateral
half of the band, rail B the back-medial half.

## 7. Haptic power rails

**[CONTRACT]** `02_HARDWARE_WIRING.md` §5.

| From | To | Capacitors |
|---|---|---|
| Switched battery + (§9) | HT7833 A — VIN | 1 µF VIN to GND |
| Switched battery + | HT7833 B — VIN | 1 µF VIN to GND |
| HT7833 A — VOUT | Rail A → M1, M2, M3 positive | 1 µF + 220 µF VOUT to GND |
| HT7833 B — VOUT | Rail B → M4, M5, M6 positive | 1 µF + 220 µF VOUT to GND |
| HT7833 A and B — GND | Common ground | — |

- **The two VOUT pins must never touch.** **[CONTRACT]**
- Motors are never powered from the XIAO's 3V3 pin.
- **HT7833 pin numbers depend on who made the part.** At least two different
  manufacturers sell a 3.3 V, 500 mA LDO marked HT7833: Holtek, and Shenzhen
  Airupton. The Airupton datasheet gives **[DS]**:

  | Package | GND | VIN | VOUT | EN |
  |---|---:|---:|---:|---:|
  | SOT-89 | 1 | 2 | 3 | — |
  | SOT-23-3 | 1 | 3 | 2 | — |
  | SOT-23-5 | 2 | 1 | 5 | 3, tie to VIN |

  Holtek's own HT78xx datasheet link is dead at the time of writing, so its
  table could not be read. The fitted part's pin order is in the update below;
  a regulator fitted backwards would put battery voltage on the motor rail.
- **Update 2026-10-02:** the ERM driver PCB uses the Holtek HT7833, SOT-89, with
  pad 1 GND, pad 2 VIN (and the tab), pad 3 VOUT, read by that project from
  Holtek HT78xx Rev 1.51 (`holtek.com/webapi/116711/HT78xxv151.pdf`) **[DS, PCB
  project]**: the same order as the Airupton SOT-89 row above.

Thermal check, worst case: full cell 4.2 V, three motors running. Dissipation
is (4.2 − 3.3) V × I. At 300 mA that is 0.27 W; a SOT-89 at 200 °C/W **[DS]**
Holtek AN0553 runs 54 °C above ambient. Acceptable for a pulsed load (motors rated
90 mA, 120 mA at start).

Operating window: dropout is 220 mV at 200 mA **[DS]** Airupton, so the rails hold
3.3 V down to a cell voltage of about 3.5 V.

## 8. Logic power

| Item | Value | Where |
|---|---|---|
| Sensor decoupling | 100 nF | At each BNO086's 3V3 pad |
| Logic rail | 10 µF | On the 3V3 line near the XIAO |
| Sensor current | 10.7 mA each at 100 Hz rotation vector (3.18 mA VDDIO + 7.50 mA VDD) | [DS] CEVA fig. 6-18 |
| Available | 700 mA from the XIAO 3V3 pin | [DS] Seeed |

Two sensors take about 22 mA of the 700 mA available. The XIAO itself draws
about 100 mA with Wi-Fi active **[DS]** Seeed.

Layout rule **[CONTRACT]**: keep the sensor region away from motor current; no
motor current under a sensor footprint; solid ground plane; wide haptic supply
and ground buses.

## 9. Power input and charging

The contract leaves this outside its scope. These are the facts that fix it:

- The XIAO has its own charger on the BAT pads, at **50 mA** fast charge
  **[DS]** Seeed spec table. That takes about 40 hours to fill a 2000 mAh cell,
  so the MCP73833 module is the practical charger.
- With two chargers on one cell, the XIAO's would also charge whenever USB-C is
  plugged into the XIAO.
- A charger cannot detect "full" while the device is drawing current from the
  same cell.

Recommended wiring, which gives one charger and a clean full-charge cut-off:

```text
                       +------------------ MCP73833 module BAT+
                       |
  Cell + (protected) --+---- SWITCH ---+---- XIAO BAT+
                                       +---- HT7833 A VIN
                                       +---- HT7833 B VIN

  Cell - --------------+------------------ MCP73833 module BAT-
                       +------------------ XIAO BAT- , HT7833 GND x2,
                                           all six MOSFET sources (common GND)
```

- **Charge with the switch OFF.** The MCP73833 then sees only the cell and
  terminates properly; the XIAO's own charger is disconnected.
- With the switch ON and USB-C in the XIAO (bench use), the XIAO's 50 mA charger
  can also reach the cell. Harmless, but avoid charging that way.
- The cell must have its own protection circuit. A body-worn lithium cell
  without one is not acceptable.
- Battery wires: heavier gauge than signal wire **[CONTRACT]**.

As built: an external master switch, the SmartElex MCP73833 module, and a cell with
its own protection board (user).

## 10. Firmware rules the wiring depends on

1. Drive all six motor GPIOs LOW as the first action in `setup()`.
2. Drive WAKE high, then pulse RST low, then wait for the first INT before
   touching the sensors. Never pulse RST while WAKE is low.
3. Enable the internal pull-up on both INT inputs, so a broken INT wire reads
   "no data", not noise.
4. Hold both CS lines high whenever the bus is idle.
5. Start the SPI bus at 1 MHz (§5).
6. Service each INT within about 1 ms — CEVA's guidance is "typically within
   1/10 of the fastest sensor period" — and never later than 10 ms, when the
   BNO086 times out and retries **[DS]** CEVA §1.2.4.1. Late service costs the
   sensor processing time and degrades its outputs.

## 11. Harnesses — conductor by conductor

No connectors in V1; conductors soldered to the board **[CONTRACT]**.

**Shank sensor — 9 conductors** (short run on the same strap):
3V3, GND, SCK, MOSI, MISO, CS_SHANK, INT_SHANK, RST, WAKE.

**Foot sensor — 10 conductors**, in this order in a flat cable, or with SCK
twisted against a ground in a round one:

| # | Signal |
|---:|---|
| 1 | GND |
| 2 | SCK |
| 3 | GND |
| 4 | MOSI |
| 5 | MISO |
| 6 | CS_FOOT |
| 7 | INT_FOOT |
| 8 | RST |
| 9 | WAKE |
| 10 | 3V3 |

**Motor band — 8 conductors:**

| # | Signal |
|---:|---|
| 1 | Rail A + — to M1, M2, M3 |
| 2 | Rail B + — to M4, M5, M6 |
| 3–8 | M1 − … M6 −, one return per motor, to its MOSFET drain |

The contract keeps the two regulator outputs apart, so each half of the band has its
own positive wire.

**Battery — 2 conductors**, heavier gauge than signal wire.

## 12. Cautions

1. **Never put a motor on GPIO39.** It comes out of reset with a 45 kΩ weak
   pull-up unless an eFuse is burnt; against the 100 kΩ gate pulldown that is
   2.3 V on the gate, above the 1.1 V maximum threshold. The motor would run
   from power-up until firmware intervened **[DS]**.
2. **3.3 V only at every sensor pad.** Absolute maximum 3.63 V **[DS]**.
3. **Diode band to the rail**, on all six channels.
4. **HT7833 pinout varies by manufacturer.** Confirm before soldering (§7).
5. **Keep rail A and rail B apart.**
6. **Never pulse RST while WAKE is low.**
7. **Plain XIAO ESP32-S3 only** — on the Sense variant the back pads are taken.
8. **The shank IMU and the motor band clamp the same bone.** Measure vibration
   pickup once the drivers are fitted (DEC-015).

## 13. Before first power-up

1. Power off: measure 3V3 to GND, rail A to GND, rail B to GND, battery + to
   GND. None may read as a short.
2. Confirm rail A and rail B are not connected to each other.
3. Confirm every diode's band faces its rail.
4. Confirm each HT7833's VIN, VOUT and GND against the seller's pinout.
5. Power on with **no motors fitted**: rails A and B read 3.3 V; each BNO086
   reads ~3.3 V on PS0, PS1 and WAKE; all six gates read ~0 V.
6. Done on 2026-10-01 (TEST-041): `firmware/bench/padstate` confirmed the pad
   states of §14 and the JTAG eFuses on this chip. Repeat it on any other XIAO
   that is used.
7. Run the bench sensor check on both sensors, then fit the motors one at a time.

## 14. Why each awkward pin carries what it carries

| Pin | Constraint | Carries | Why that is safe |
|---|---|---|---|
| GPIO39 | Weak pull-up after reset unless EFUSE_DIS_PAD_JTAG is burnt **[DS]** | Foot INT, an input | A pull-up suits an input that idles high |
| GPIO3 | Strapping pin; 60 µs low glitch at power-up **[DS]** | WAKE | Only selects the JTAG source if an eFuse is burnt; the boards' own pull-ups set WAKE's boot level |
| GPIO43/44 | UART0; GPIO43 carries the ROM boot log | Chip selects | Internal pull-ups keep them high; with no clock on SCK the boot-log wiggle transfers nothing |
| GPIO40, 41, 42 | Nothing — no pull, not strapping, no power-up glitch **[DS]** | Shank INT, RST, Motor 3 | Clean pins |
| GPIO1, 2, 4, 5, 6 | 60 µs **low** glitch at power-up **[DS]** | Motors 1, 2, 4, 5, 6 | Low is "off"; none has an internal pull |

### Conflict check

Every rule a pin can break, checked against the final map.

| Check | Result | Evidence |
|---|---|---|
| Every GPIO used exactly once | **Pass** — 1, 2, 3, 4, 5, 6, 7, 8, 9, 39, 40, 41, 42, 43, 44 | — |
| No motor pin has an internal pull-up | **Pass** — GPIO1, 2: input-enable only; 4, 5, 6: nothing; 42: input-enable only after reset | [DS] Table 2-1 |
| No motor pin glitches high at power-up | **Pass** — GPIO1–6 glitch low only; GPIO42 has no glitch | [DS] Table 2-2 |
| GPIO39's pull-up lands on an input | **Pass** — foot INT | [DS] Table 2-1 note 7 |
| Back pads not connected to the JTAG controller | **Pass, measured** — eFuses read 0 on the chip (TEST-041); with them at factory default, JTAG goes to the USB Serial/JTAG controller, so the foot sensor's INT on MTCK cannot clock a JTAG state machine and MTDO is never driven against the shank INT | [DS] Table 3-5 |
| GPIO3's strap role inert | **Pass, measured** — "Ignored" with the eFuses at factory default, which TEST-041 confirmed | [DS] Table 3-5, [MEAS] |
| Boot-mode straps GPIO0, 45, 46 untouched | **Pass** | [DS] Table 3-1 |
| USB pins GPIO19/20 untouched | **Pass** | [DS] |
| Flash and octal-PSRAM pins GPIO26–37 untouched | **Pass** | ESP-IDF GPIO docs |
| Chip selects high through boot | **Pass** — GPIO43/44 have internal pull-ups | [DS] Table 2-1 |
| Boot log on GPIO43 reaching the foot CS | **No effect** — no clock on SCK; the shank CS stays high, so MISO is never contested | [DS] |
| Two sensors sharing SCK, MISO and MOSI | **Supported by the manufacturer** — "Multiple slave devices can exist on a SPI interface by the use of a chip select signal"; MISO is driven only after CS falls (CS-to-MISO 31 ns). Proven on these boards only by bring-up step 3, both sensors together | [DS] CEVA §1.2.4.2, §6.5.2 |
| One sensor on MISO at a time | **Firmware rule** — never assert both CS together | §10 |
| Sensors come up in SPI mode | **Pass** — both boards hold PS0/WAKE and PS1 high | [DS] CEVA §1.2.4, [USER] |
| RST held high through boot | **Pass** — 10 kΩ on each board | [USER] |
| PWM channels | **Pass** — 6 used of 8 | [DS] |
| 3V3 budget | **Pass** — about 22 mA of 700 mA | [DS] CEVA, Seeed |
| UART0 never started | **Firmware rule** — starting it would reclaim GPIO43/44 from the chip selects | — |
| Board variant | **Plain XIAO ESP32-S3 only** — on the Sense the back pads drive the camera | [DS] Seeed |

**Measured on the chip (TEST-041, 2026-10-01):** all three JTAG eFuses read 0,
the factory value, so the three rows that depend on them are confirmed. Every
motor pin has neither pull-up nor pull-down; both chip-select pins have their
pull-ups and sit high. GPIO39's pull-up is already off when user code runs, but
the pad still reads high with nothing attached: the pull-up was on from reset,
the window in which a motor there would have switched on.

## 15. What is wired today

**As built, power (user, 2026-10-02):** the switched LOAD+ goes to the ERM
driver's PWR+ and to the XIAO's **5V pin**, not to BAT+ as §9 and the PCB design
specify. Seeed: the 5V pin is USB VBUS and needs an external diode when used as an
input **[vendor doc]**. **Never turn the master
switch ON while USB is plugged into the XIAO.**

**Current device (user, 2026-10-02): the DEC-016 build of §3, with the ERM driver
PCB of §6, everything fitted.** Motors rewired to a new pin order on 2026-10-07
(user; §6, DEC-029).

**Previous device, no longer exists.** Two MPU6500s on I²C.

| Function | XIAO pin | GPIO |
|---|---|---:|
| I²C SDA | D4 | 5 |
| I²C SCL | D5 | 6 |
| Foot INT (address 0x68) | D8 | 7 |
| Shank INT (address 0x69) | D9 | 8 |
| Motor outputs, held LOW, nothing connected | D0, D1, D3, D10, D6, D7 | 1, 2, 4, 9, 43, 44 |

**Bench — one BNO086** (edge pins only; not the product layout):
3V3→3V3, GND→GND, SCK→D8, MISO→D9, MOSI→D10, CS→D3, INT→D2, RST→D1, WAKE→D0.

## 16. Sources

| Source | Used for |
|---|---|
| Espressif, ESP32-S3 Series Datasheet v2.2 — Tables 2-1, 2-2, 3-1, 5-4 | Pad states at and after reset, glitches, strapping, pull resistors, drive current |
| ESP-IDF GPIO documentation, ESP32-S3 | Pin restrictions |
| Seeed Studio, XIAO ESP32-S3 wiki | Back pads, BAT pad polarity, 50 mA charge current, 700 mA 3V3 output, 5V pin on battery |
| CEVA, BNO08X Datasheet 1000-3927 v1.17 | Pin functions, SPI-mode strapping, power, absolute maxima, INT timeout |
| 7Semi, BNO086 breakout manual ES-12143 v1.0 | Pad names |
| Infineon, IRLML6344 datasheet v01_01 | Pinout, gate threshold, on-resistance |
| Shenzhen Airupton, HT78XX datasheet V1.0 | HT7833 pinout by package, dropout |
| Holtek, AN0553 application note | SOT-89 thermal resistance, capacitor use |
| `ead_agent_docs_v2/02, 03, 06, 17` | Motor channel, rails, band angles, parts |
| TEST-039, TEST-040 | Measured board behaviour |

---

*This document is the source for `EAD_V1_wiring_reference.pdf`. Rebuild it with:*

```bash
pandoc docs/wiring_reference.md -t html5 --standalone --css=style.css \
  --metadata title="EAD V1 wiring reference" -o wiring.html
libreoffice --headless --convert-to pdf wiring.html
```

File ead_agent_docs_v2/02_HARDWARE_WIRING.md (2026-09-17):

# 02 — Hardware Wiring

## 1. Scope
This file is the authoritative firmware-facing electrical interface. It deliberately excludes charger, battery protection, fuse/PTC, and power-management implementation because those are outside the software agent's responsibility.

## 2. MPU6050 shared I²C bus
Both MPU6050 boards share the same I²C lines.

```text
XIAO GPIO5 / D4 (SDA) ----+---- Foot MPU6050 SDA
                           +---- Shank MPU6050 SDA

XIAO GPIO6 / D5 (SCL) ----+---- Foot MPU6050 SCL
                           +---- Shank MPU6050 SCL
```

Power:
```text
XIAO 3V3 ---- Foot MPU VCC
           └- Shank MPU VCC
XIAO GND ---- Foot MPU GND
           └- Shank MPU GND
```

Addresses:
- Foot AD0 -> GND -> `0x68`.
- Shank AD0 -> 3V3 -> `0x69`.

The user has confirmed the MPU6050 breakout boards already have I²C pull-ups. The firmware assumes the existing pull-ups and does not require another external pull-up network.

## 3. MPU interrupts
- Foot MPU `INT` -> XIAO GPIO7 / D8.
- Shank MPU `INT` -> XIAO GPIO8 / D9.
- Configure both for data-ready interrupt.
- The acquisition task timestamps samples from the ESP32 monotonic clock; do not timestamp them on laptop receipt.

## 4. Motor channel
Every ERM is low-side switched by one IRLML6344.

```text
3V3_HAPTIC --- ERM +
                 ERM - --- Drain(Qx)
                             Source(Qx) --- GND_HAPTIC
ESP32 PWM --- 100R --- Gate(Qx)
Gate(Qx) --- 100k --- GND
```

Flyback diode:
```text
1N5819W across ERM
Cathode/stripe -> ERM + / 3V3_HAPTIC
Anode -> ERM - / MOSFET drain
```

Optional 10 nF motor suppression capacitor footprint is allowed but **DNP by default**; populate only if EMI/noise testing shows benefit and it does not destabilize the motor rail.

## 5. Haptic rail division
- HT7833 rail A -> motors M1, M2, M3.
- HT7833 rail B -> motors M4, M5, M6.
- Outputs of the two HT7833 regulators MUST NOT be tied together.
- One 220 µF bulk capacitor on each haptic rail.
- 1 µF input and output decoupling per HT7833.

The firmware does not control or monitor the regulators.

## 6. Logic decoupling
- Place at least 100 nF close to each MPU6050 supply.
- Use the XIAO board's own required local decoupling as supplied by the module.

## 7. Physical wiring rule
Keep the IMU signal/power region physically separated from high-current motor paths. Do not route motor current traces underneath the MPU6050 footprint if avoidable. Use a solid/common ground plane on the PCB and wide haptic supply/ground buses.

## 8. No connectors in V1
The PCB does not require dedicated JST/headers for the motors or XIAO. The user will solder stripped pre-crimped wire harness conductors directly to the board.

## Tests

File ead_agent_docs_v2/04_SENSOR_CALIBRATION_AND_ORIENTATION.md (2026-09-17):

# 04 — Sensor Calibration and Orientation

## 1. Coordinate convention
Both IMUs use the same anatomical frame:
- **X+ = forward, toward the toes**.
- **Y+ = medial/left for the right leg, toward the big-toe/inner-leg side**.
- **Z+ = up, away from the ground**.

The supplied placement image is the physical assembly reference. Do not mirror the shank sensor or rotate one board 180° relative to the other.

## 2. Installation requirement
The boards should be:
- flat against the body segment as much as practical;
- rigidly attached;
- aligned with each other;
- mechanically repeatable between sessions.

Small installation angle error is handled by alignment calibration, but gross misorientation is not acceptable.

## 3. Startup static calibration
### Step A — sensor health
1. Confirm both I²C addresses answer (`0x68`, `0x69`).
2. Read `WHO_AM_I` and verify expected MPU6050 identity.
3. Read multiple samples and reject a sensor if values are frozen, NaN/invalid, or outside physical bounds.

### Step B — stationary bias estimate
Place the user standing still and keep both sensors still for **5 seconds**.
- Require low angular-rate variance.
- Require acceleration magnitude close to 1 g.
- Estimate gyro bias from the stationary mean.
- Estimate accelerometer bias after accounting for the expected gravity vector in the installed coordinate frame.
- Save calibration quality metrics.

If motion occurs during calibration, discard the window and request another 5-second stationary period.

## 4. Alignment calibration
After static bias estimation, derive an alignment rotation from the measured gravity vector and the known anatomical orientation. The alignment should make the gravity vector point to +Z while preserving the defined forward/medial directions. Do not use the magnetometer because MPU6050 has none.

The alignment transform is stored with the session/device calibration record.

## 5. Orientation algorithm
Use a **Mahony 6-DoF attitude estimator** separately for each IMU.
- Input: calibrated accelerometer + calibrated gyroscope.
- Update: 100 Hz.
- Gravity is used to correct roll/pitch.
- Yaw is gyro-integrated and therefore drift-prone.
- No absolute heading is claimed.
- Relative foot/shank orientation is the preferred kinematic representation for rotation features.

V1 gains:
- `Kp = 2.0`
- `Ki = 0.05`

Keep the gain values in configuration so engineering tests can tune them, but ship these values as the V1 default.

## 6. Relative orientation
Represent segment-relative orientation as:
```text
q_relative = inverse(q_shank) * q_foot
```
Use the relative orientation for ankle/foot-segment features. Normalize quaternions after each update.

For V1 analysis, do not use absolute yaw as a clinical feature.

## 7. Filtering layers
Maintain separate paths:
- **raw path:** unmodified calibrated measurements for storage.
- **orientation path:** Mahony input, lightly filtered for estimator stability.
- **gait path:** 2nd-order low-pass IIR/biquad at 6 Hz for gait timing/features.
- **event path:** preserve enough bandwidth for contact/transient detection; use the 20 Hz cleaned sensor path.

Never overwrite the canonical raw data with filtered values.

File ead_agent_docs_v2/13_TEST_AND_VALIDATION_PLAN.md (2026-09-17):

# 13 — Test and Validation Plan

## 1. Hardware bring-up tests
1. Verify both MPU6050 devices enumerate at `0x68` and `0x69`.
2. Verify no I²C address collision.
3. Verify 100 Hz frame cadence over a 5-minute run.
4. Verify both INT lines generate data-ready events.
5. Verify all six PWM outputs stay LOW at boot.
6. Verify each motor independently.
7. Verify flyback diode polarity physically before motor testing.
8. Verify haptic safety cutoff after 5 s continuous command.

## 2. Sensor tests
- 5-minute static log: accel magnitude should remain close to 1 g.
- gyro bias stability check.
- controlled axis rotations to verify X/Y/Z signs.
- verify both sensors use the same anatomical orientation.
- compare relative orientation during known foot/shank rotations.

## 3. Gait algorithm tests
Use recorded datasets and replay them deterministically.
Test:
- normal walking;
- slow walking;
- variable cadence;
- intentional dorsiflexion deviation;
- plantarflexion deviation;
- inversion/eversion deviation;
- temporary sensor noise;
- dropped samples;
- static periods;
- invalid sensor values.

## 4. ZUPT tests
Confirm that:
- valid foot-flat intervals are detected;
- false ZUPTs are rejected during swing;
- velocity drift is materially reduced;
- poor-quality sessions are flagged instead of silently reporting fabricated distance.

## 5. Haptic tests
Confirm:
- no haptic on low confidence;
- larger error yields larger PWM;
- intensity falls as error falls;
- OFF threshold is below ON threshold;
- correct spatial motor pair is selected;
- timing error uses temporal dual-pole cue;
- 5 s maximum continuous ON is enforced;
- rolling 10 s duty limit is enforced.

## 6. Wireless tests
- disconnect Wi-Fi for 60 s while walking;
- verify gait/haptic continues;
- reconnect;
- verify missing telemetry is backfilled from storage when available;
- verify no duplicate cycle IDs.

## 7. Storage tests
- power/reset during block write;
- corrupt payload CRC;
- truncate final block;
- reboot;
- verify automatic recovery to last valid block.

## 8. Dashboard tests
- live charts;
- event markers;
- raw-to-error traceability;
- export CSV;
- export `.mat`;
- PDF report;
- session segmentation;
- reference lock.

## 9. Replay requirement
A saved raw dataset plus fixed configuration must reproduce the same:
- gait events;
- cycle features;
- error score;
- error class;
- haptic decisions.

This deterministic replay requirement is mandatory for algorithm development and regression testing.

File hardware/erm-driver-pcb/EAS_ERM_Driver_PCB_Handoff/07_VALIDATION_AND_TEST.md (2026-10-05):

# Assembly, Bring-Up, and Validation Procedure

## 1. Visual inspection before power
Confirm:
- No copper bridges between the two 3.3 V rails.
- No solder bridges at MOSFET SOT-23 pins.
- All SOD-123 diode orientations match the schematic.
- HT7833 package orientation/pinout is correct.
- 220 uF polymer polarity is correct.
- No accidental short between `SWITCHED_SYSTEM+` and GND.
- Motor pads are clearly labeled.

## 2. Unpowered resistance checks
With no battery/USB attached:
- Measure `SWITCHED_SYSTEM+` to `GND`; verify there is no hard short.
- Measure `HAPTIC_3V3_A` to GND.
- Measure `HAPTIC_3V3_B` to GND.
- Verify `HAPTIC_3V3_A` to `HAPTIC_3V3_B` is not a direct short.
- Verify each gate is not shorted to source/drain.

## 3. Regulator-only bring-up
Disconnect all six motors initially.

Use a current-limited bench supply set to a single-cell-compatible voltage, initially around 3.7-4.0 V.

Power the board and verify:
- `SWITCHED_SYSTEM+` reaches both HT7833 inputs.
- `HAPTIC_3V3_A` is approximately 3.3 V while input is sufficiently above dropout and load is light.
- `HAPTIC_3V3_B` is approximately 3.3 V under the same condition.
- The regulators do not heat abnormally with no motor load.

## 4. One-motor test
Connect only one motor to one channel.

Drive the channel from the ESP32 at low duty cycle first.

Verify:
- motor is OFF at PWM=0;
- motor starts cleanly;
- motor stops when PWM is removed;
- MOSFET remains cool;
- no ESP32 reset occurs.

## 5. Channel-by-channel test
Repeat the one-motor test for all six channels.

Confirm channel mapping:
- PWM1 -> M1
- PWM2 -> M2
- PWM3 -> M3
- PWM4 -> M4
- PWM5 -> M5
- PWM6 -> M6

## 6. Three-motor rail test
Run M1-M3 simultaneously, then M4-M6 simultaneously.

Observe:
- regulator temperature;
- rail voltage;
- unexpected noise/resets;
- diode/capacitor temperature;
- PCB hot spots.

## 7. Six-motor test
Run all six motors with a controlled duty cycle. Test both steady vibration and the intended haptic PWM pattern.

If an oscilloscope is available, probe:
- `HAPTIC_3V3_A` near U1 output capacitor;
- `HAPTIC_3V3_B` near U2 output capacitor;
- one MOSFET drain switching node;
- ESP32 3.3 V rail separately;
- ground bounce between ESP32 ground and the driver board's high-current ground region.

The exact acceptable transient limits should be established during prototype validation rather than invented in the PCB documentation.

## 8. Battery discharge test
Because HT7833 is a linear 3.3 V regulator, regulation will eventually be lost as a single-cell LiPo approaches the 3.3 V output level. This is expected behavior for this V1.

Characterize motor vibration strength as battery voltage decreases and document the practical operating window. Do not treat low-battery rail droop as a PCB failure unless it occurs unexpectedly above the expected dropout region.

## 9. Charging test
Test with the master switch OFF:
- connect USB to MCP73833;
- verify battery charges normally;
- verify driver PCB and ESP32 remain OFF.

Then, only after the above works, test switch ON while charging. Treat simultaneous charge + load as a secondary condition and verify charger/load behavior empirically.

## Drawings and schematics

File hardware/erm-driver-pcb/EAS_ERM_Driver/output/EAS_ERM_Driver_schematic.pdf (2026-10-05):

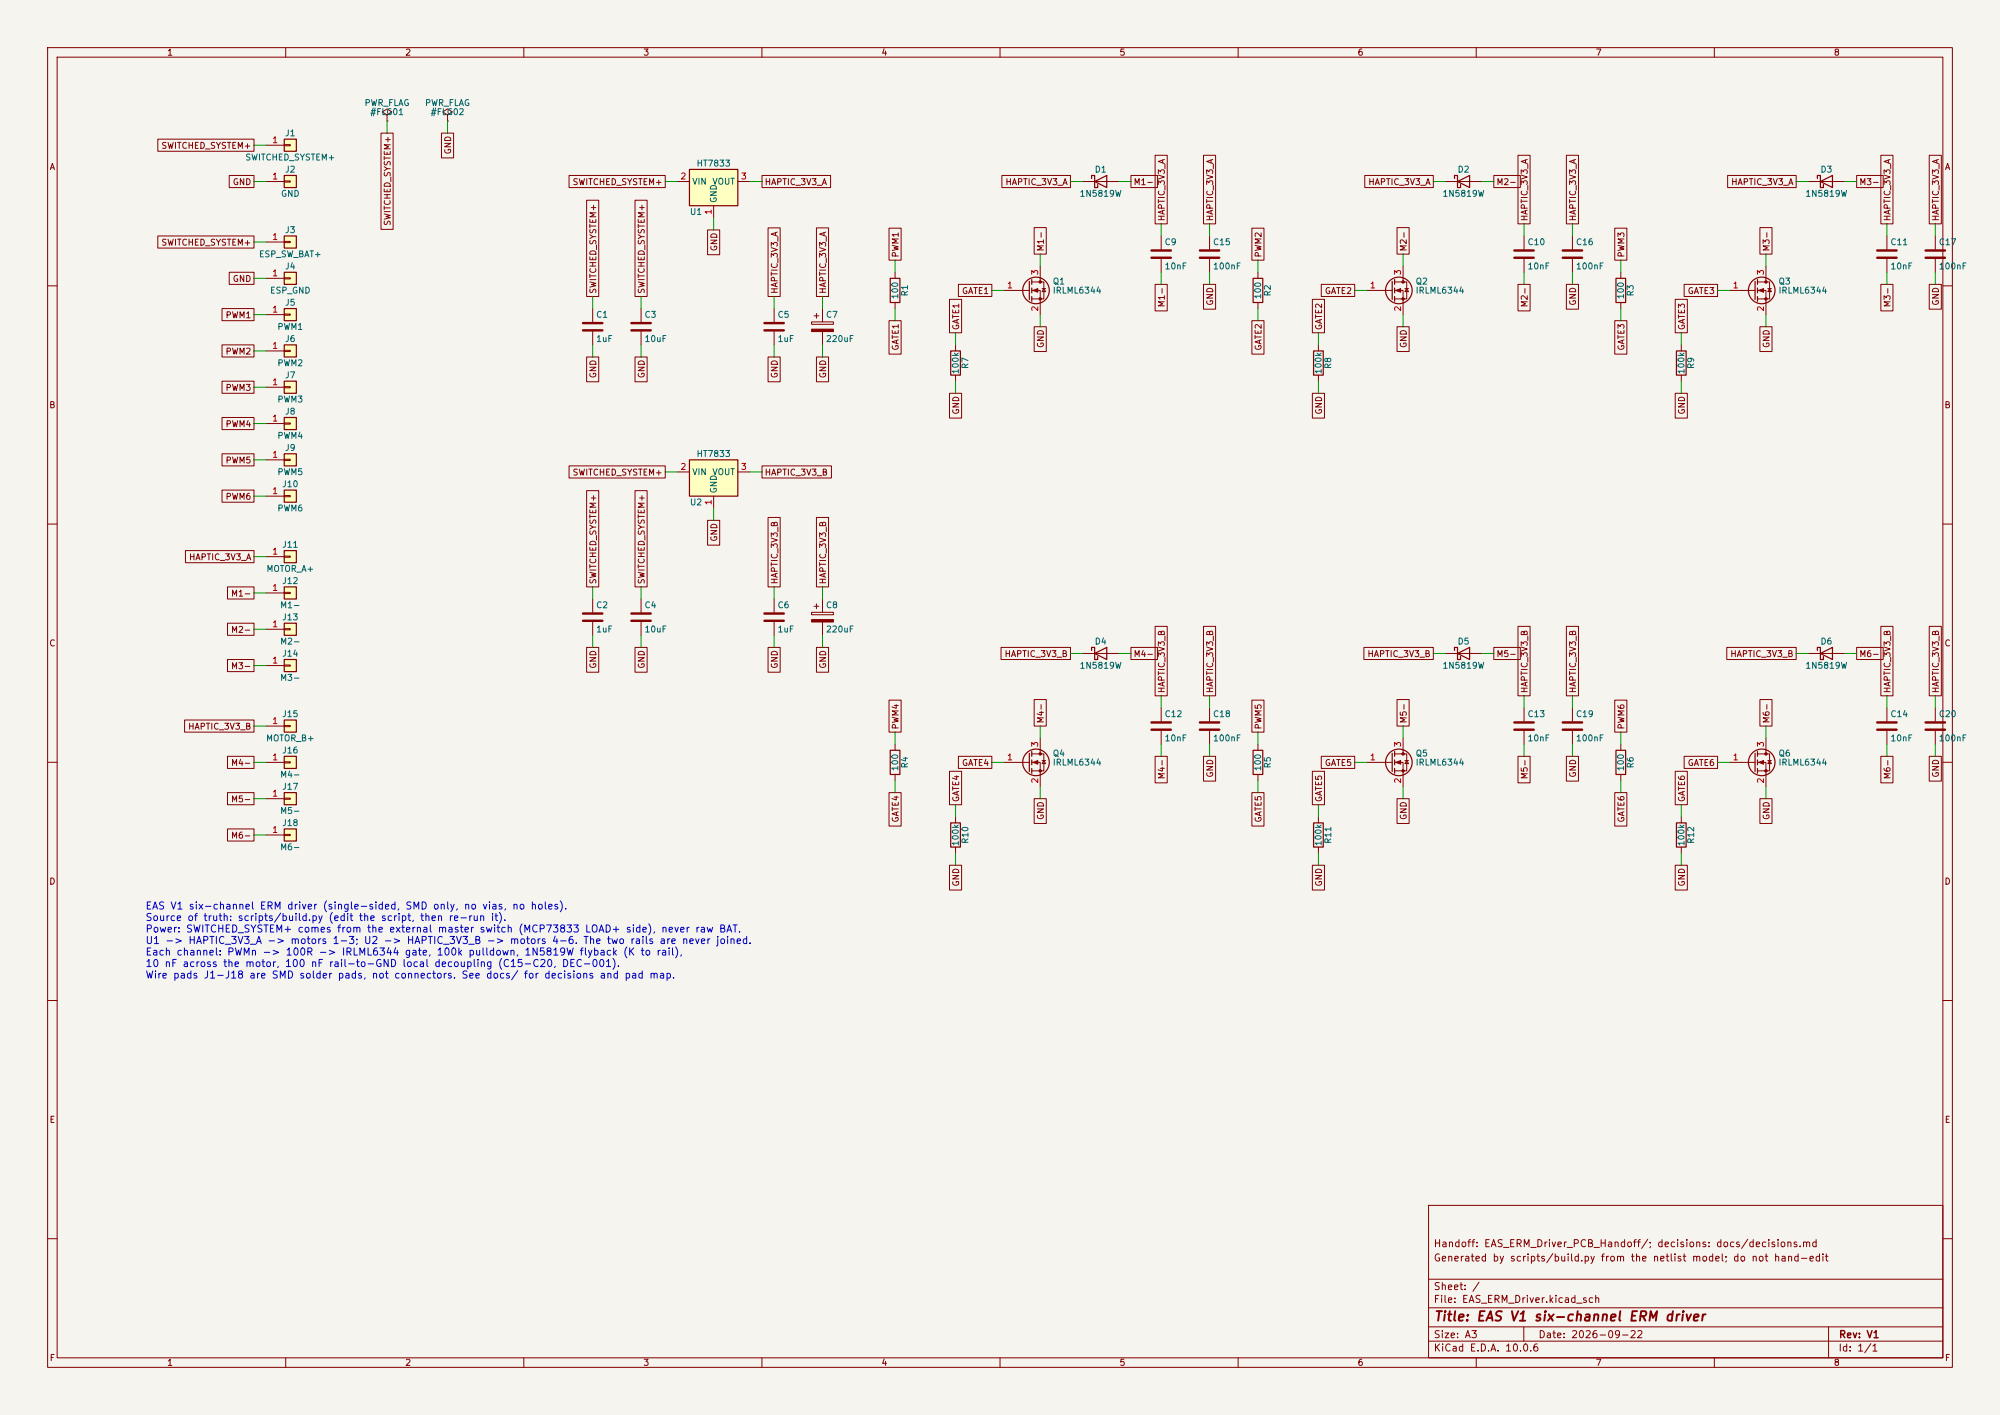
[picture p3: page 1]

Handoff: EAS_ERM_Driver_PCB_Handoff/; decisions: docs/decisions.md 100k R12

EAS V1 six-channel ERM driver (single-sided, SMD only, no vias, no holes).
Source of truth: scripts/build.py (edit the script, then re-run it).
Power: SWITCHED_SYSTEM+ comes from the external master switch (MCP73833 LOAD+ side), never raw BAT.
U1 -> HAPTIC_3V3_A -> motors 1-3; U2 -> HAPTIC_3V3_B -> motors 4-6. The two rails are never joined.
Each channel: PWMn -> 100R -> IRLML6344 gate, 100k pulldown, 1N5819W flyback (K to rail),
10 nF across the motor, 100 nF rail-to-GND local decoupling (C15-C20, DEC-001).
Wire pads J1-J18 are SMD solder pads, not connectors. See docs/ for decisions and pad map.

Generated by scripts/build.py from the netlist model; do not hand-edit

Sheet: /
File: EAS_ERM_Driver.kicad_sch
Title: EAS V1 six-channel ERM driver

Size: A3 | Rev: V1 | F Date: 2026-09-22
KiCad E.D.A. 10.0.6 | Id: 1/1

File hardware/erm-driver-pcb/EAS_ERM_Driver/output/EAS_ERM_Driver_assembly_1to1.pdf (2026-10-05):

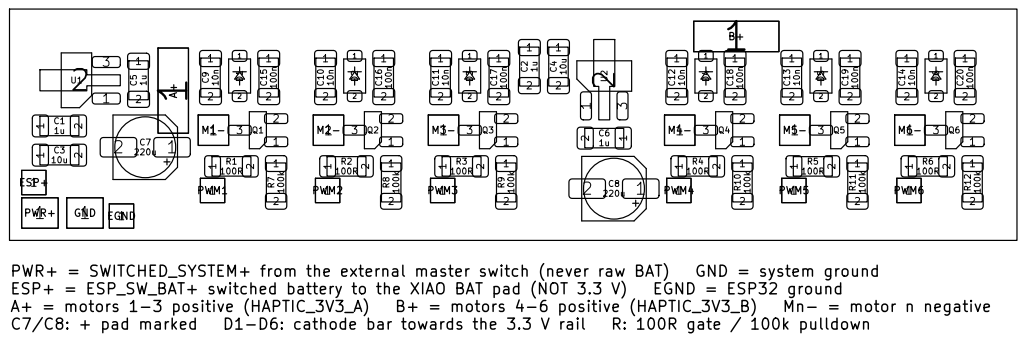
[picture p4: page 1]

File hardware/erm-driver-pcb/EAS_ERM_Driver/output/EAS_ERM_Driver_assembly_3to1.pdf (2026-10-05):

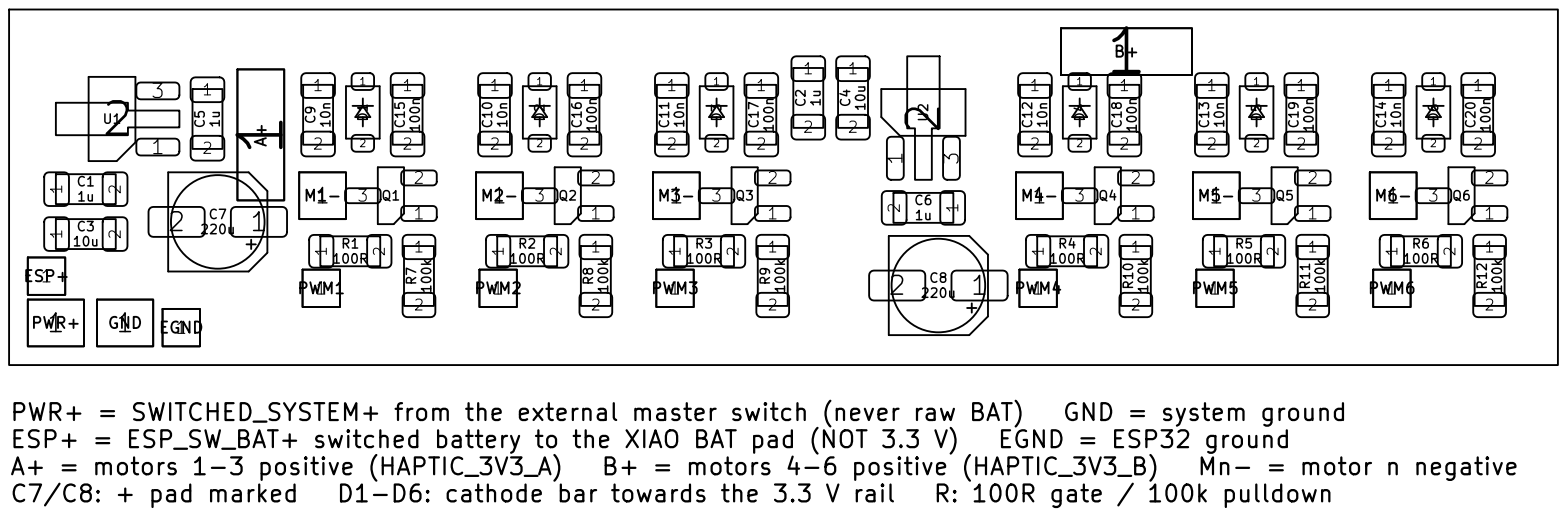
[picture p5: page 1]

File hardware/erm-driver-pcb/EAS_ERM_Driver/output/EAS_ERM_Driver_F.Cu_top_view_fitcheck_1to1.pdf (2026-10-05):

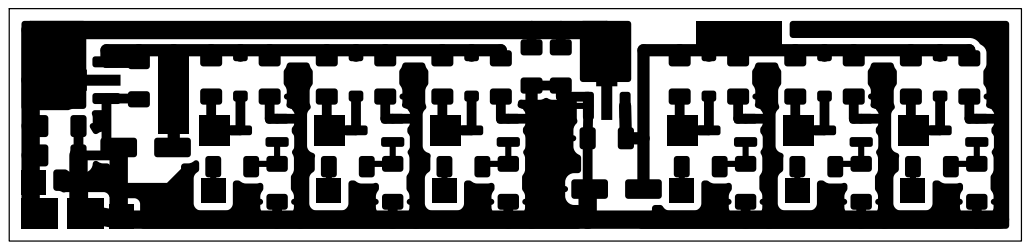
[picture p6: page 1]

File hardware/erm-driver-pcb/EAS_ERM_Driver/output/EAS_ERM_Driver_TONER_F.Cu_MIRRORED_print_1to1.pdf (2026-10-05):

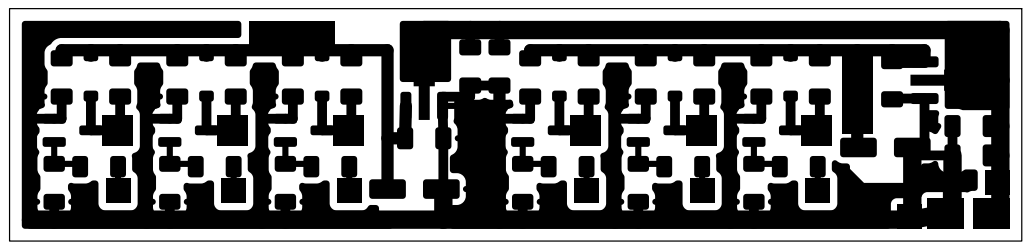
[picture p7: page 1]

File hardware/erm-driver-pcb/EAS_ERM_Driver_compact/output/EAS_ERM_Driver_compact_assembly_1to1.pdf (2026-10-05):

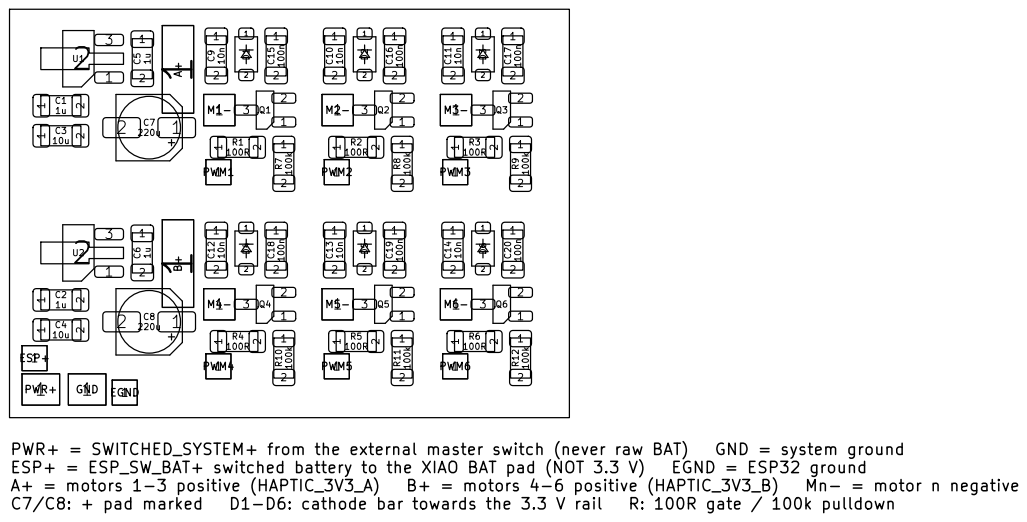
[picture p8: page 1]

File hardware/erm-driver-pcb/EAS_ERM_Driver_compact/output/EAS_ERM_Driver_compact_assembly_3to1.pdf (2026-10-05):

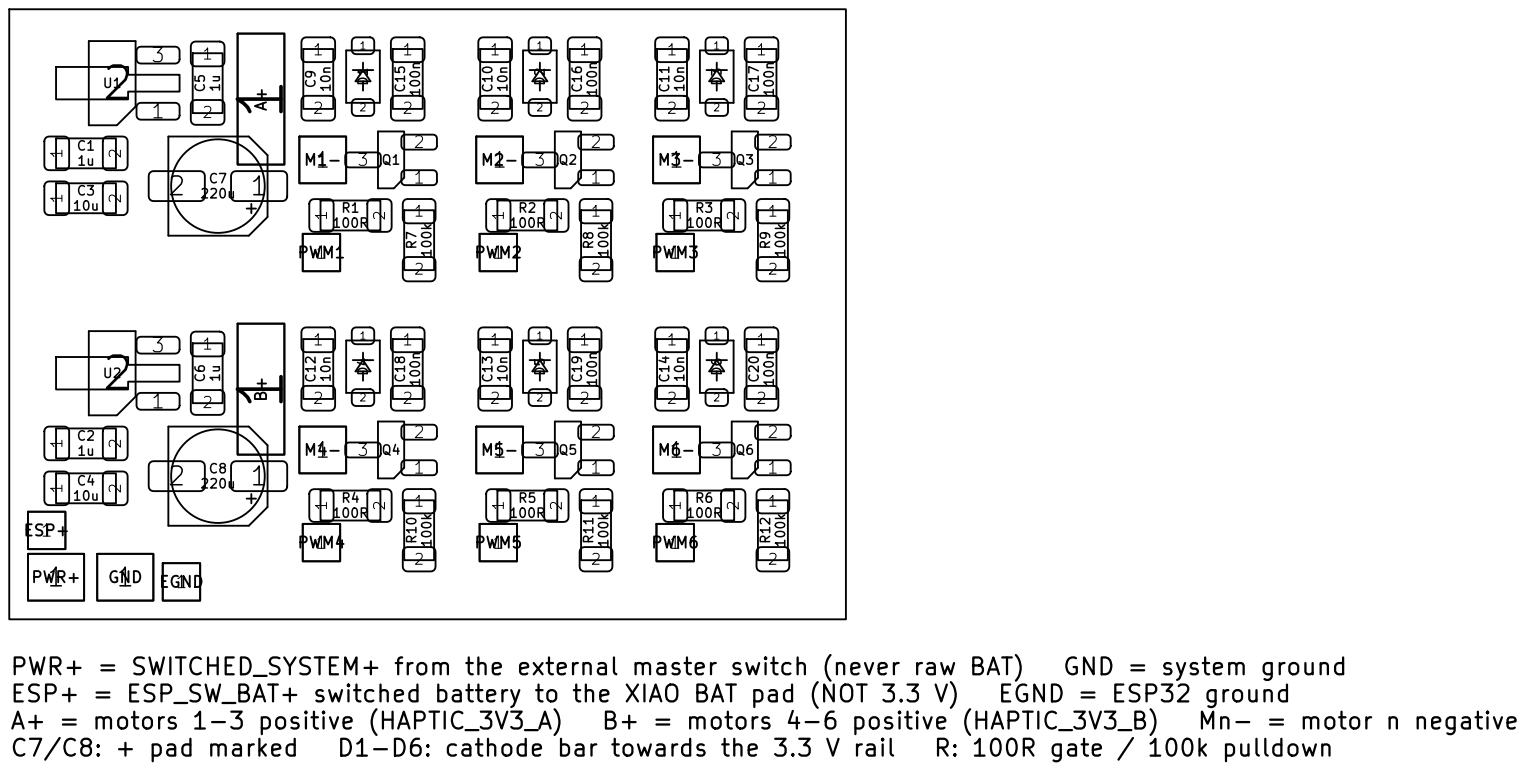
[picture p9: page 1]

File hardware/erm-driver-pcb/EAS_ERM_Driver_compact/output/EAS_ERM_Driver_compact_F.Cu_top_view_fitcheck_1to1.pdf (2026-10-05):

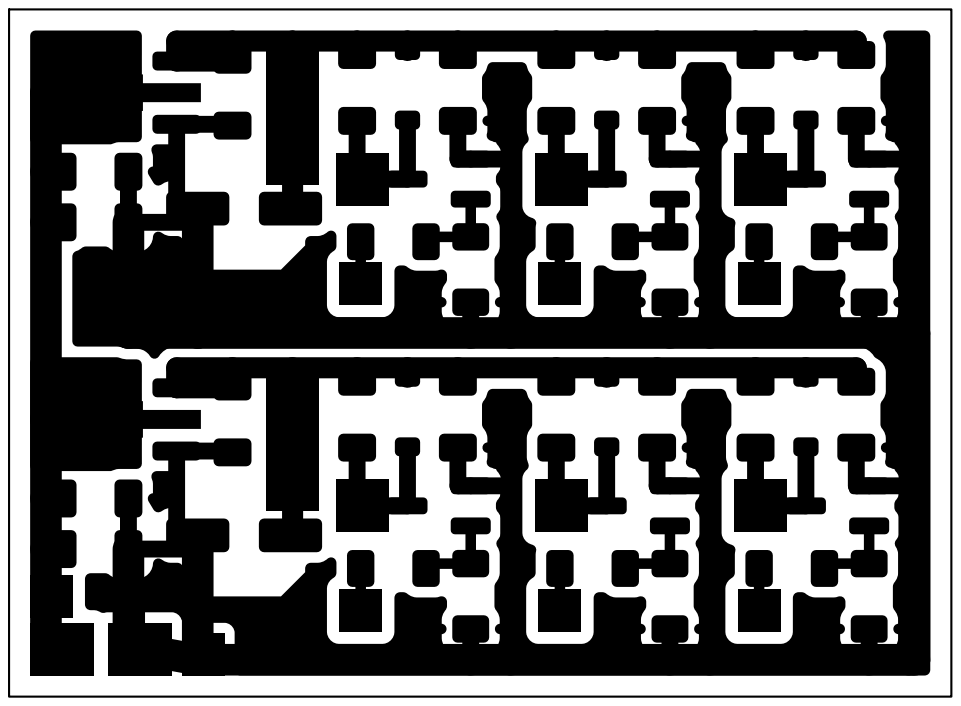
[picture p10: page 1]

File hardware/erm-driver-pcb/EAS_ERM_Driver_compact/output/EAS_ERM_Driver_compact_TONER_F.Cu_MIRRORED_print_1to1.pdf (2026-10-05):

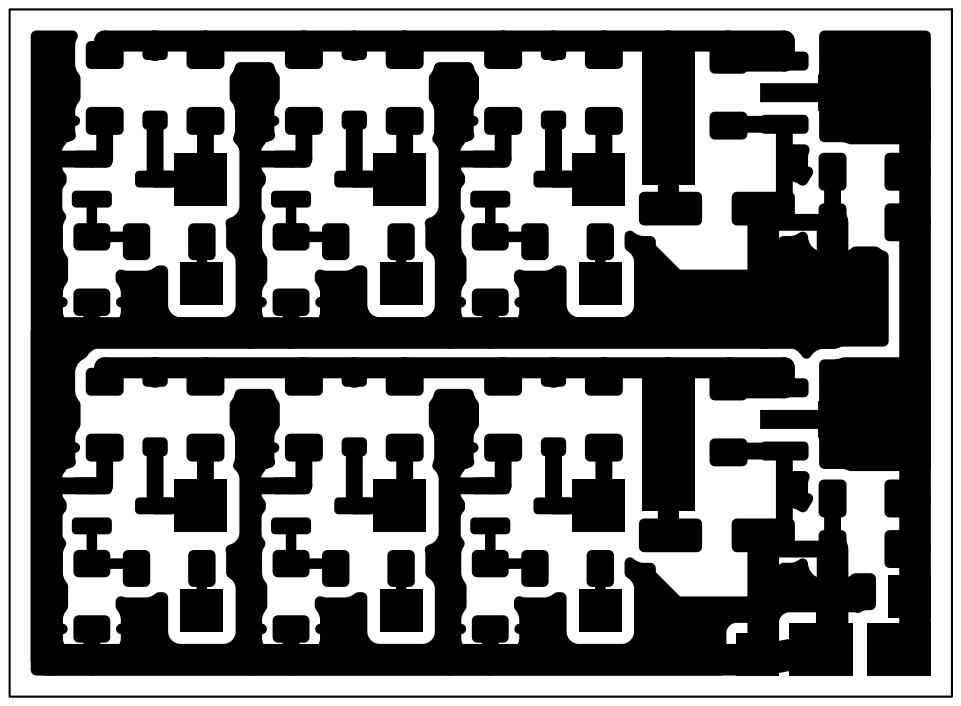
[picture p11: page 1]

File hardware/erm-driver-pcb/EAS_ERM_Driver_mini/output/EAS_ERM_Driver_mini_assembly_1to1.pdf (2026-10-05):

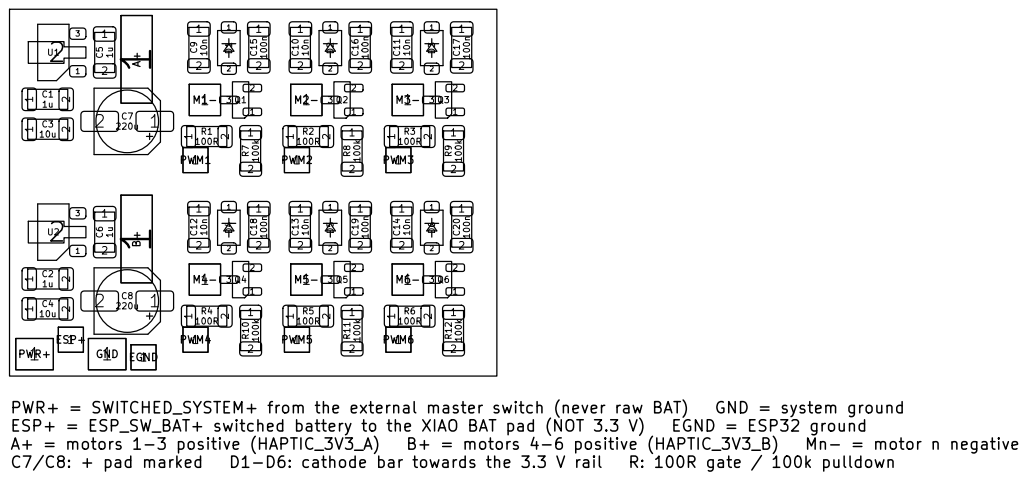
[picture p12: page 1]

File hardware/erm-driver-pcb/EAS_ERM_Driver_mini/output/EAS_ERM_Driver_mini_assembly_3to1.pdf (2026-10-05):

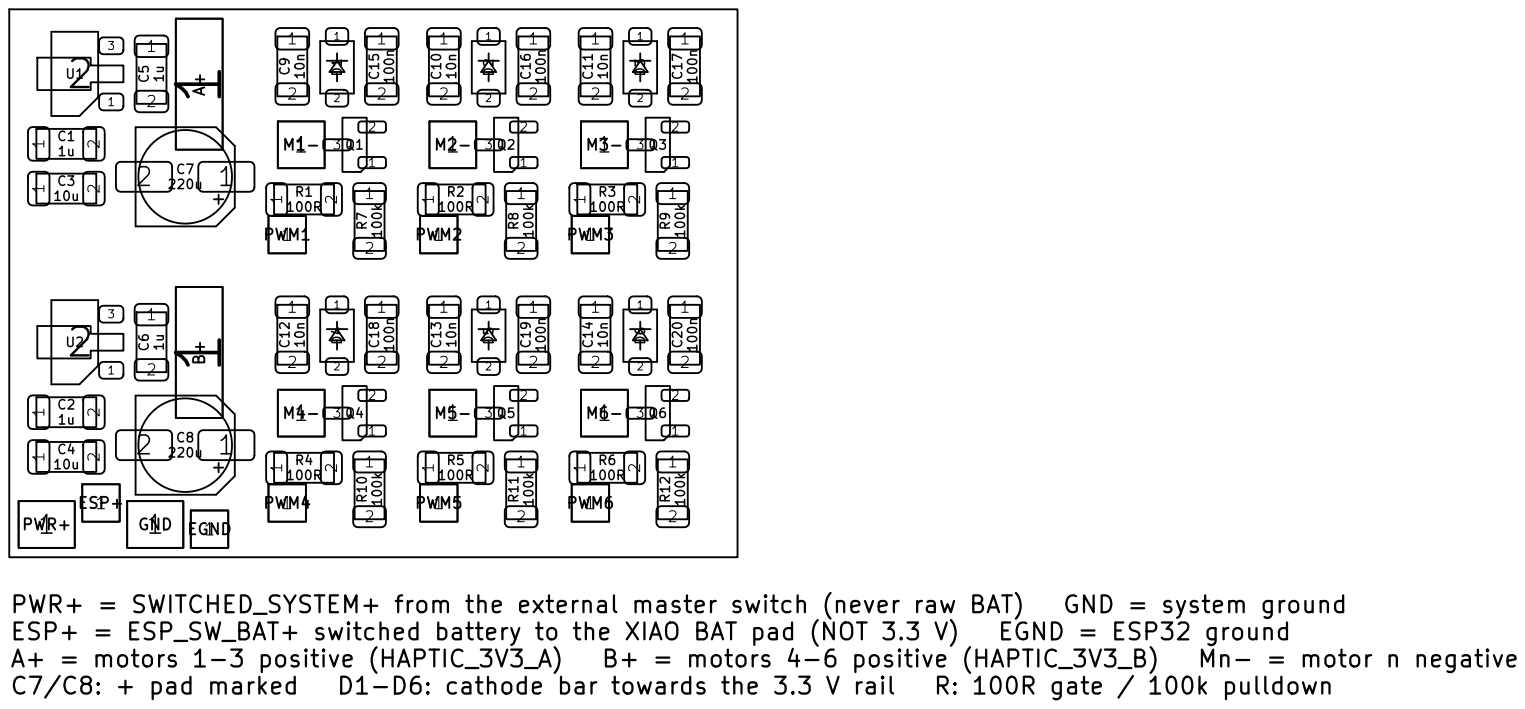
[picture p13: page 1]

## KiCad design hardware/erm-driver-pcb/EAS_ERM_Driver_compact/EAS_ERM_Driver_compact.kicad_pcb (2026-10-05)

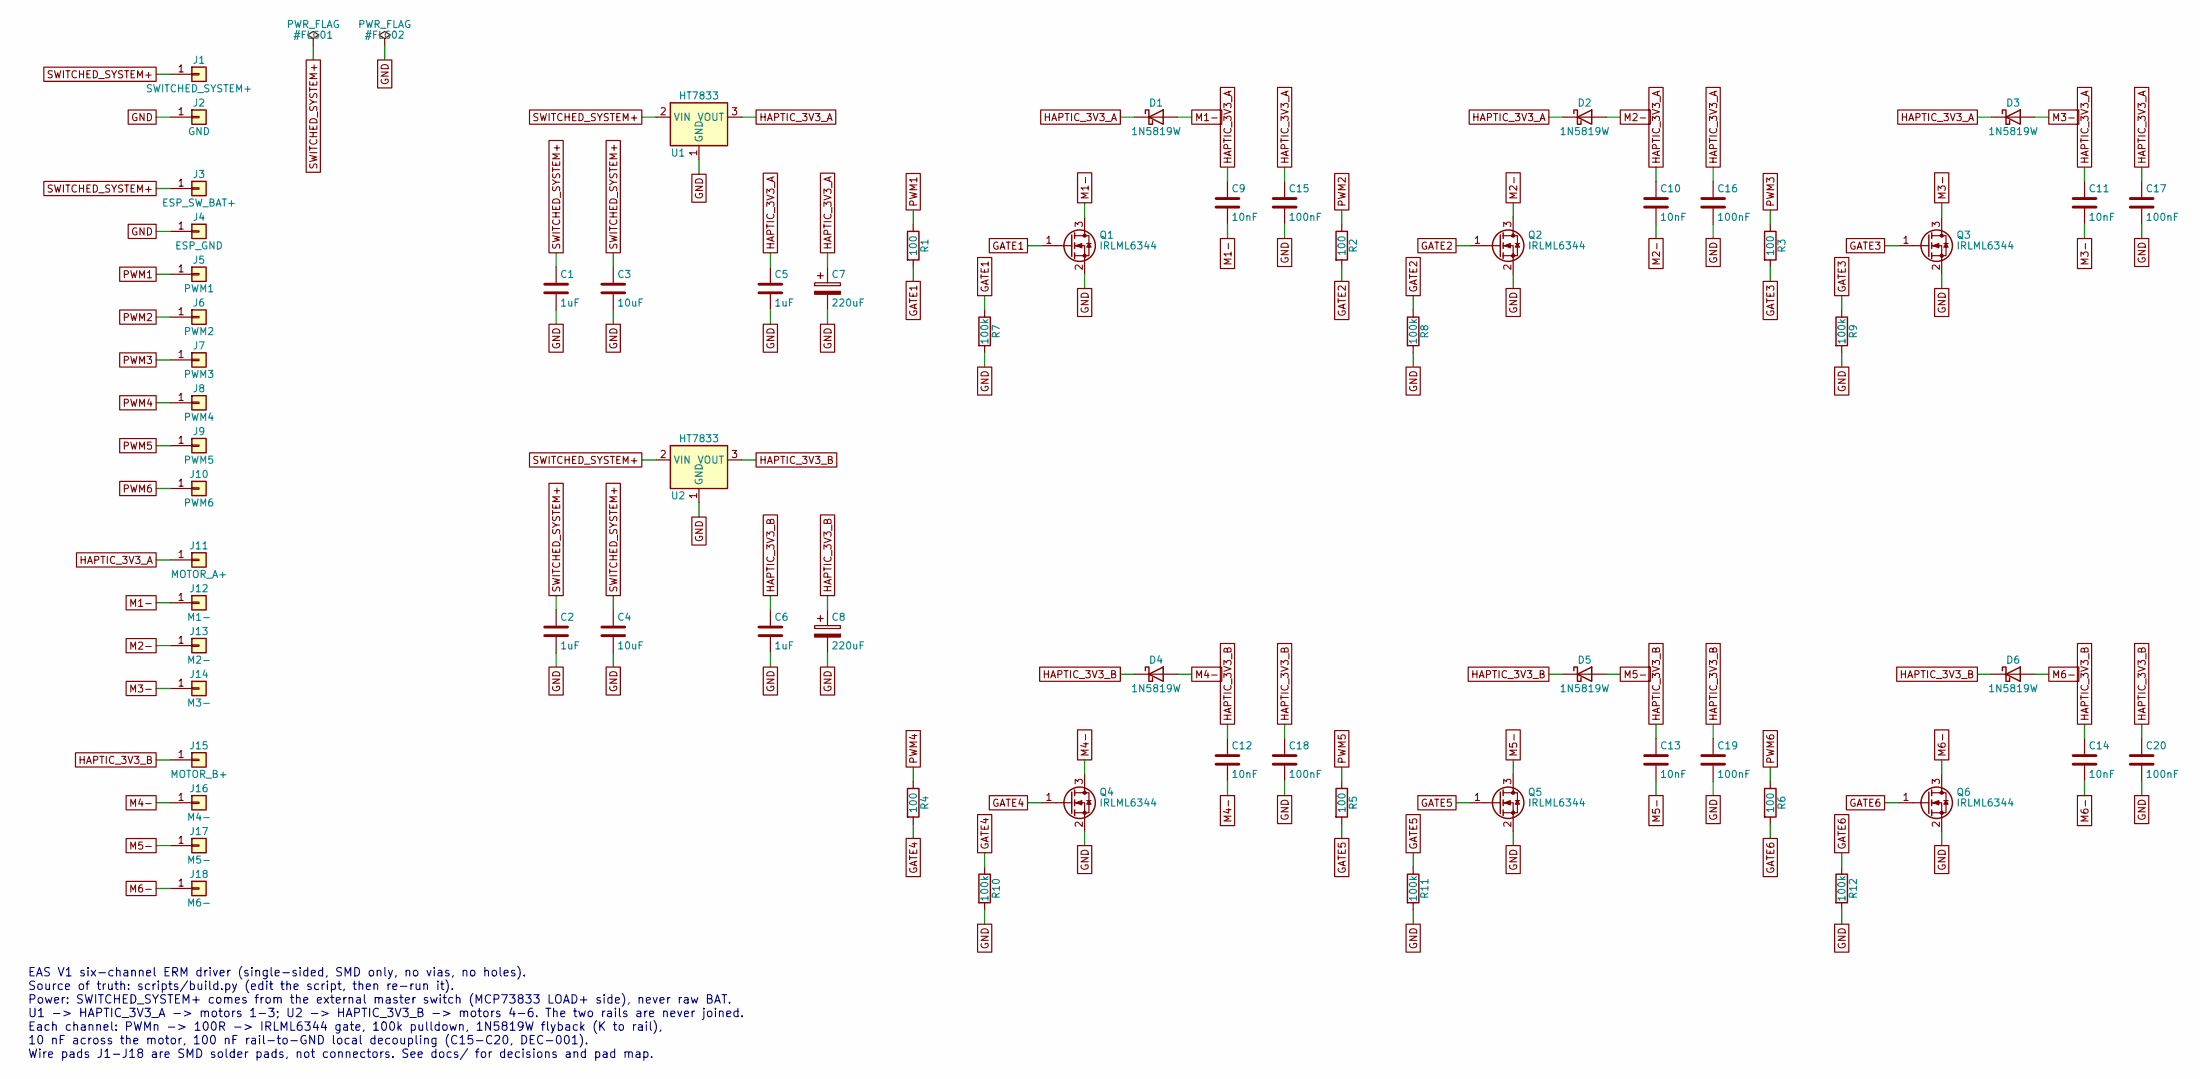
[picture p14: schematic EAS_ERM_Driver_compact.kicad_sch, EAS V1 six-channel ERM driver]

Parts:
C1, C2, C5, C6: 1uF; C_1206_3216Metric_Pad1.33x1.80mm_HandSolder
C3, C4: 10uF; C_1206_3216Metric_Pad1.33x1.80mm_HandSolder
C7, C8: 220uF; CP_Elec_5x5.9
C9, C10, C11, C12, C13, C14: 10nF; C_1206_3216Metric_Pad1.33x1.80mm_HandSolder
C15, C16, C17, C18, C19, C20: 100nF; C_1206_3216Metric_Pad1.33x1.80mm_HandSolder
D1, D2, D3, D4, D5, D6: 1N5819W; D_SOD-123
J1: SWITCHED_SYSTEM+; WirePad_3.0x2.5mm
J2: GND; WirePad_3.0x2.5mm
J3: ESP_SW_BAT+; WirePad_2.0x2.0mm
J4: ESP_GND; WirePad_2.0x2.0mm
J5: PWM1; WirePad_2.0x2.0mm
J6: PWM2; WirePad_2.0x2.0mm
J7: PWM3; WirePad_2.0x2.0mm
J8: PWM4; WirePad_2.0x2.0mm
J9: PWM5; WirePad_2.0x2.0mm
J10: PWM6; WirePad_2.0x2.0mm
J11: MOTOR_A+; WirePad_2.5x7.0mm
J12: M1-; WirePad_2.5x2.5mm
J13: M2-; WirePad_2.5x2.5mm
J14: M3-; WirePad_2.5x2.5mm
J15: MOTOR_B+; WirePad_2.5x7.0mm
J16: M4-; WirePad_2.5x2.5mm
J17: M5-; WirePad_2.5x2.5mm
J18: M6-; WirePad_2.5x2.5mm
Q1, Q2, Q3, Q4, Q5, Q6: IRLML6344; SOT-23_Handsoldering
R1, R2, R3, R4, R5, R6: 100; R_1206_3216Metric_Pad1.30x1.75mm_HandSolder
R7, R8, R9, R10, R11, R12: 100k; R_1206_3216Metric_Pad1.30x1.75mm_HandSolder
U1, U2: HT7833; SOT-89-3_Handsoldering_0.4mm

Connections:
GATE1: Q1.1 (G), R1.2, R7.1
GATE2: Q2.1 (G), R2.2, R8.1
GATE3: Q3.1 (G), R3.2, R9.1
GATE4: Q4.1 (G), R4.2, R10.1
GATE5: Q5.1 (G), R5.2, R11.1
GATE6: Q6.1 (G), R6.2, R12.1
GND: C1.2, C2.2, C3.2, C4.2, C5.2, C6.2, C7.2, C8.2, C15.2, C16.2, C17.2, C18.2, C19.2, C20.2, J2.1, J4.1, Q1.2 (S), Q2.2 (S), Q3.2 (S), Q4.2 (S), Q5.2 (S), Q6.2 (S), R7.2, R8.2, R9.2, R10.2, R11.2, R12.2, U1.1 (GND), U2.1 (GND)
HAPTIC_3V3_A: C5.1, C7.1, C9.1, C10.1, C11.1, C15.1, C16.1, C17.1, D1.1 (K), D2.1 (K), D3.1 (K), J11.1, U1.3 (VOUT)
HAPTIC_3V3_B: C6.1, C8.1, C12.1, C13.1, C14.1, C18.1, C19.1, C20.1, D4.1 (K), D5.1 (K), D6.1 (K), J15.1, U2.3 (VOUT)
M1-: C9.2, D1.2 (A), J12.1, Q1.3 (D)
M2-: C10.2, D2.2 (A), J13.1, Q2.3 (D)
M3-: C11.2, D3.2 (A), J14.1, Q3.3 (D)
M4-: C12.2, D4.2 (A), J16.1, Q4.3 (D)
M5-: C13.2, D5.2 (A), J17.1, Q5.3 (D)
M6-: C14.2, D6.2 (A), J18.1, Q6.3 (D)
PWM1: J5.1, R1.1
PWM2: J6.1, R2.1
PWM3: J7.1, R3.1
PWM4: J8.1, R4.1
PWM5: J9.1, R5.1
PWM6: J10.1, R6.1
SWITCHED_SYSTEM+: C1.1, C2.1, C3.1, C4.1, J1.1, J3.1, U1.2 (VIN), U2.2 (VIN)

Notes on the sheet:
EAS V1 six-channel ERM driver (single-sided, SMD only, no vias, no holes). Source of truth: scripts/build.py (edit the script, then re-run it). Power: SWITCHED_SYSTEM+ comes from the external master switch (MCP73833 LOAD+ side), never raw BAT. U1 -> HAPTIC_3V3_A -> motors 1-3; U2 -> HAPTIC_3V3_B ->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

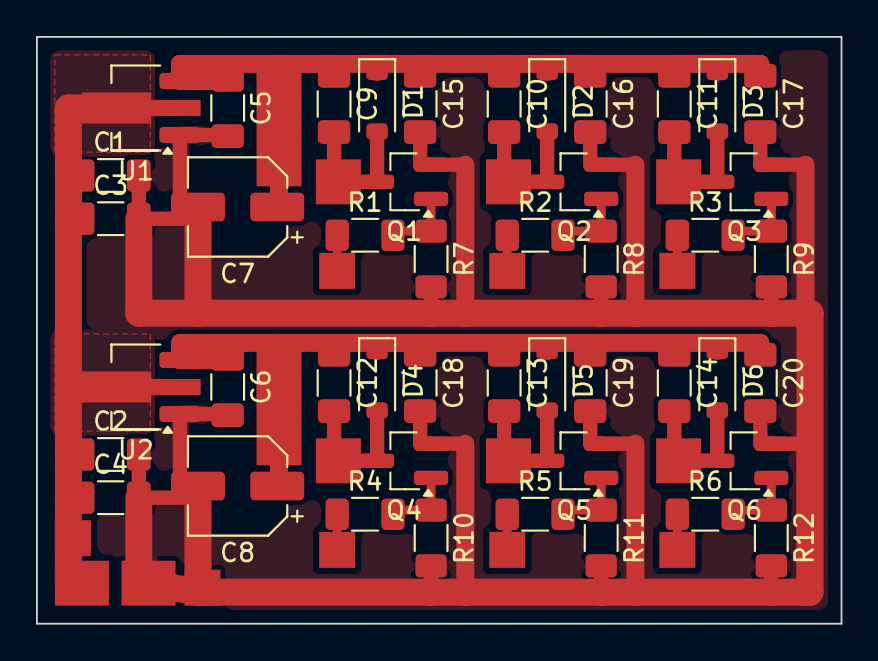
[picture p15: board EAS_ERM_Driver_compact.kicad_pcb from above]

Board: 2 copper layers, 44.7 x 32.6 mm, 64 parts (0 on the bottom side), 22 nets.

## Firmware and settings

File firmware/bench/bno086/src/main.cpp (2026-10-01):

// EAD-V1 bench test — the BNO086s on the final DEC-016 wiring, one at a time.
//
// Not product firmware. Purpose, in order:
//   1. check the wiring of every GPIO going to the sensor,
//   2. read the sensor's identity so a relabelled / wrong part shows up,
//   3. stream orientation so tools/bno_view.py can show how it is tilted.
//
// Wiring: docs/wiring_reference.md (DEC-016): both sensors share SCK, MISO,
// MOSI, RST and WAKE; each has its own CS and INT. Motor gates sit on six of
// the XIAO's pins, so this firmware drives them LOW before anything else and
// never touches them again.
//
// One sensor per build (env:foot, env:shank): the SparkFun library keeps its
// pins in file-scope globals and CEVA's sh2.c inside it has a single global
// instance, so it cannot run two sensors at once. The other sensor's CS is
// held high throughout, so it never drives MISO.
//
// Output: one line per event on USB CDC.
//   CHK,<name>,<PASS|FAIL|INFO>,<detail>
//   ID,<entry>,part=<n>,ver=<a.b.c>,build=<n>,reset_cause=<n>
//   D,<t_ms>,<qi>,<qj>,<qk>,<qr>,<acc_deg>,<ax>,<ay>,<az>,<gx>,<gy>,<gz>
//   # <free text>

#include <Arduino.h>
#include <SPI.h>
#include <hal/usb_serial_jtag_ll.h>
#include <SparkFun_BNO08x_Arduino_Library.h>

namespace {

#if defined(EAD_BENCH_SENSOR_FOOT)
constexpr const char* kSensor = "foot";
constexpr uint8_t kPinCs = 43;        // D6
constexpr uint8_t kPinInt = 39;       // MTCK back pad
constexpr uint8_t kPinOtherCs = 44;   // D7, shank
constexpr uint8_t kPinOtherInt = 40;  // MTDO back pad, shank
#elif defined(EAD_BENCH_SENSOR_SHANK)
constexpr const char* kSensor = "shank";
constexpr uint8_t kPinCs = 44;
constexpr uint8_t kPinInt = 40;
constexpr uint8_t kPinOtherCs = 43;
constexpr uint8_t kPinOtherInt = 39;
#else
#error "build env:foot or env:shank"
#endif
constexpr uint8_t kPinRst = 41;   // MTDI back pad, both sensors
constexpr uint8_t kPinWake = 3;   // D2, both sensors' PS0/WAKE net
// Motors 1, 2, 3, 4, 5, 6 (DEC-016). A floating gate is pulled off by its
// 100 kOhm resistor, but driving it LOW does not depend on that.
constexpr uint8_t kMotorPins[] = {1, 2, 42, 4, 5, 6};

constexpr bool isMotorPin(uint8_t pin) {
  for (uint8_t motor : kMotorPins) {
    if (motor == pin) return true;
  }
  return false;
}
static_assert(!isMotorPin(kPinCs) && !isMotorPin(kPinInt) && !isMotorPin(kPinOtherCs) &&
                  !isMotorPin(kPinOtherInt) && !isMotorPin(kPinRst) && !isMotorPin(kPinWake) &&
                  !isMotorPin(SCK) && !isMotorPin(MISO) && !isMotorPin(MOSI),
              "a sensor line on a motor gate would switch the motor");

// docs/wiring_reference.md firmware rule 5: start at 1 MHz on the long foot
// cable; 3 MHz (the BNO08x maximum) only after a soak test on the harness.
constexpr uint32_t kSpiHz = 1000000;
constexpr uint16_t kReportMs = 10;    // 100 Hz, the rate the product uses

BNO08x imu;

// The checks run once, at boot. A serial monitor is usually opened after that,
// so every line is kept and re-sent when the host asks (any byte, see loop()).
String transcript;
bool stopped = false;

// Arduino's HWCDC Serial prints nothing on this board (docs/problems.md
// PROB-006, and measured again here: a bare Serial.println sketch produced no
// bytes). Like firmware/src/link_usb.cpp, this writes the USB Serial/JTAG IN
// endpoint directly: one packet at a time, and never appending to a packet the
// host has not collected yet, which duplicated bytes.
constexpr uint32_t kPacket = 64;

bool inEndpointEmpty() { return USB_SERIAL_JTAG.int_raw.serial_in_empty_int_raw; }

void usbWrite(const char* data, size_t len) {
  static bool inFlight = false;
  size_t pos = 0;
  while (pos < len) {
    if (inFlight) {
      uint32_t waited = 0;
      while (!inEndpointEmpty() && waited < 200) {
        delay(1);
        waited++;
      }
      if (!inEndpointEmpty()) return;  // no host reading; drop the rest
      inFlight = false;
    }
    const size_t want = len - pos < kPacket ? len - pos : kPacket;
    const uint32_t accepted =
        usb_serial_jtag_ll_write_txfifo(reinterpret_cast<const uint8_t*>(data + pos), want);
    if (accepted == 0) return;
    pos += accepted;
    usb_serial_jtag_ll_clr_intsts_mask(USB_SERIAL_JTAG_INTR_SERIAL_IN_EMPTY);
    usb_serial_jtag_ll_txfifo_flush();
    inFlight = true;
  }
}

void usbPrint(const String& text) { usbWrite(text.c_str(), text.length()); }

bool usbAsked() {
  if (!usb_serial_jtag_ll_rxfifo_data_available()) return false;
  uint8_t drain[kPacket];
  while (usb_serial_jtag_ll_rxfifo_data_available()) usb_serial_jtag_ll_read_rxfifo(drain, kPacket);
  return true;
}

void emit(const String& line) {
  transcript += line;
  transcript += '\n';
  usbPrint(line + "\n");
}

void chk(const char* name, bool pass, const String& detail) {
  emit(String("CHK,") + name + "," + (pass ? "PASS" : "FAIL") + "," + detail);
}

void info(const char* name, const String& detail) {
  emit(String("CHK,") + name + ",INFO," + detail);
}

// Reads a line back with the ESP32's own pull-up and then its pull-down.
// 1/0 means nothing outside is holding the line: the wire goes only to the
// sensor's high-impedance pin. 1/1 means an external pull-up (the breakout
// has them on PS0/WAKE and RST). 0/0 means the line is held low, which on a
// bench is almost always a short to GND or a swapped wire.
String readBack(uint8_t pin) {
  pinMode(pin, INPUT_PULLUP);
  delayMicroseconds(200);
  const int high = digitalRead(pin);
  pinMode(pin, INPUT_PULLDOWN);
  delayMicroseconds(200);
  const int low = digitalRead(pin);
  pinMode(pin, INPUT);
  return String(high) + "/" + String(low);
}

// Waits for an INT line to reach `level`, returns the time it took, or -1 on
// timeout.
int32_t waitInt(uint8_t pin, int level, uint32_t timeoutMs) {
  const uint32_t start = millis();
  while (millis() - start < timeoutMs) {
    if (digitalRead(pin) == level) return int32_t(millis() - start);
    delay(1);
  }
  return -1;
}

// Every line except power, before any SPI traffic. The sensor is held in
// reset so it drives nothing and cannot answer.
bool checkWiring() {
  pinMode(kPinWake, OUTPUT);
  digitalWrite(kPinWake, HIGH);  // PS0 must be HIGH at reset or the part
                                 // comes up in a UART mode, not SPI.
  pinMode(kPinRst, OUTPUT);
  digitalWrite(kPinRst, LOW);
  delay(20);

  pinMode(kPinInt, INPUT_PULLUP);
  pinMode(kPinOtherInt, INPUT_PULLUP);  // wiring rule 6: pull-ups on both INT lines
  const bool intIdle = digitalRead(kPinInt) == HIGH;
  const bool otherIdle = digitalRead(kPinOtherInt) == HIGH;
  chk("int_idle_in_reset", intIdle,
      intIdle ? "INT high while RST low" : "INT stuck low: short to GND, or INT on the wrong pin");

  // 1/1 = an external pull-up. On this breakout SCK, MISO and MOSI are the
  // same chip pins as SCL, SDA and SA0, which carry the board's I2C pull-ups,
  // so 1/1 is normal there. 0/0 on any line means it is held low: a short to
  // GND, or a wire on the wrong pin.
  info("readback_miso", readBack(MISO) + " (1/0 floating, 1/1 pulled up, 0/0 held low = fault)");
  info("readback_cs", readBack(kPinCs) + " (same reading)");
  info("readback_sck", readBack(SCK) + " (same reading)");
  info("readback_mosi", readBack(MOSI) + " (same reading)");

  pinMode(kPinCs, OUTPUT);
  digitalWrite(kPinCs, HIGH);

  // RST and INT together: releasing reset must make the sensor boot and
  // announce itself by pulling INT low. RST is shared, so the other sensor
  // boots too; its INT is reported as well, without talking to it.
  pinMode(kPinInt, INPUT_PULLUP);
  digitalWrite(kPinRst, HIGH);
  const int32_t t = waitInt(kPinInt, LOW, 500);
  const bool otherBooted = waitInt(kPinOtherInt, LOW, 500) >= 0;
  info("other_rst_int", String("other sensor INT ") + (otherIdle ? "high" : "LOW") +
                            " in reset, " + (otherBooted ? "low" : "still HIGH") +
                            " after release (expected: high, then low)");
  if (t >= 0) {
    chk("rst_int", true, "INT asserted " + String(t) + " ms after reset released");
    return true;
  }
  chk("rst_int", false,
      "INT never went low after reset: check 3V3, GND, RST, INT, and that PS0/PS1 are unsoldered");
  return false;
}

void printIds() {
  for (uint8_t i = 0; i < imu.prodIds.numEntries; i++) {
    const sh2_ProductId_t& e = imu.prodIds.entry[i];
    char line[128];
    snprintf(line, sizeof(line), "ID,%u,part=%lu,ver=%u.%u.%u,build=%lu,reset_cause=%u", i,
             (unsigned long)e.swPartNumber, e.swVersionMajor, e.swVersionMinor,
             e.swVersionPatch, (unsigned long)e.swBuildNumber, e.resetCause);
    emit(line);
  }
  info("id_entries", String(imu.prodIds.numEntries) +
                         " entries (a BNO08x answers the SH-2 product ID request; a part that"
                         " cannot is not running CEVA/Hillcrest firmware)");
}

// What the part says about its own hardware, which is stronger evidence than the
// firmware version alone: each sensor's SH-2 metadata carries the vendor's name
// and part number for the MEMS behind it, plus its range and resolution, and the
// FRS holds a per-unit serial number. A relabelled or cloned part cannot produce
// a consistent set of these.
void checkIdentity() {
  struct Probe { const char* name; sh2_SensorId_t id; };
  static const Probe kProbes[] = {
      {"accel", SH2_ACCELEROMETER},
      {"gyro", SH2_GYROSCOPE_CALIBRATED},
      {"mag", SH2_MAGNETIC_FIELD_CALIBRATED},
      {"rotation_vector", SH2_ROTATION_VECTOR},
  };
  for (const Probe& p : kProbes) {
    sh2_SensorMetadata_t meta;
    const int status = sh2_getMetadata(p.id, &meta);
    if (status != SH2_OK) {
      info((String("meta_") + p.name).c_str(), "SH-2 error " + String(status));
      continue;
    }
    // vendorId is length-counted, not necessarily terminated.
    char vendor[49];
    const uint32_t len = meta.vendorIdLen < sizeof(vendor) - 1 ? meta.vendorIdLen : sizeof(vendor) - 1;
    memcpy(vendor, meta.vendorId, len);
    vendor[len] = '\0';
    info((String("meta_") + p.name).c_str(),
         String("vendor=\"") + vendor + "\" range=" + meta.range + " res=" + meta.resolution +
             " min_period_us=" + meta.minPeriod_uS + " me=" + meta.meVersion + " mh=" +
             meta.mhVersion + " sh=" + meta.shVersion + " q=" + meta.qPoint1);
  }

  uint32_t serial[8] = {0};
  uint16_t words = 8;
  const int frs = sh2_getFrs(SERIAL_NUMBER, serial, &words);
  if (frs == SH2_OK && words > 0) {
    String text;
    for (uint16_t i = 0; i < words; i++) text += String(serial[i]) + " ";
    info("serial_number", text + "(" + String(words) + " words)");
  } else {
    info("serial_number", "SH-2 error " + String(frs) + ", words=" + String(words));
  }

  sh2_OscType_t osc = SH2_OSC_INTERNAL;
  const int oscStatus = sh2_getOscType(&osc);
  info("oscillator", oscStatus == SH2_OK
                         ? String(osc) + " (0 internal, 1 external crystal, 2 external clock)"
                         : "SH-2 error " + String(oscStatus));
}

// The three things the CEVA datasheet lists as BNO086-only, as far as they can be
// reached over SPI:
//   - Interactive Calibration: the Motion Intent command and the Motion Request
//     report (datasheet: "MI - Motion Intent - BNO086 only", "MR - Motion Request
//     - BNO086 only"). A part without them rejects the command or the report.
//   - 14-bit accelerometer: measured from the raw accelerometer counts. If the
//     data were 12-bit in a 16-bit field the low bits would always be zero, so
//     every count would be a multiple of 4.
//   - Lower idle power: needs a current meter, so it is not testable here.
void check086() {
  const int intent = sh2_setIZro(SH2_IZRO_MI_STATIONARY_NO_VIBRATION);
  chk("izro_motion_intent", intent == SH2_OK,
      intent == SH2_OK ? "accepted (Interactive Calibration, BNO086 only)"
                       : "SH-2 error " + String(intent));

  const bool mr = imu.enableReport(SH2_IZRO_MOTION_REQUEST, 100000);
  String seen = mr ? "report enabled" : "report refused";
  if (mr) {
    const uint32_t start = millis();
    while (millis() - start < 2000) {
      if (imu.getSensorEvent() && imu.getSensorEventID() == SH2_IZRO_MOTION_REQUEST) {
        seen += ", request=" + String(imu.sensorValue.un.izroRequest.request) +
                " intent=" + String(imu.sensorValue.un.izroRequest.intent);
        break;
      }
    }
    imu.enableReport(SH2_IZRO_MOTION_REQUEST, 0);
  }
  chk("izro_motion_request", mr, seen);

  // How many bits the accelerometer data really carries. The BMA280 puts 14-bit
  // data in the top bits of a 16-bit field, so the counts come out as multiples
  // of 4; what matters is the step size relative to full scale. Held still the
  // vector magnitude is 1 g, so counts-per-g times the full-scale range (8 g
  // either way, from the metadata above) gives the usable count range.
  // The raw report only flows while the calibrated accelerometer runs, which by
  // now it does.
  if (!imu.enableReport(SH2_RAW_ACCELEROMETER, kReportMs)) {
    chk("accel_bits", false, "raw accelerometer report refused");
    return;
  }
  uint32_t divisor = 0, n = 0;
  double magSum = 0;
  const uint32_t start = millis();
  while (millis() - start < 2000) {
    if (!imu.getSensorEvent() || imu.getSensorEventID() != SH2_RAW_ACCELEROMETER) continue;
    const int16_t axis[3] = {imu.getRawAccelX(), imu.getRawAccelY(), imu.getRawAccelZ()};
    for (int16_t v : axis) {
      uint32_t a = uint32_t(v < 0 ? -int32_t(v) : int32_t(v)), b = divisor;
      while (a != 0) { const uint32_t t = b % a; b = a; a = t; }  // gcd
      divisor = b;
    }
    magSum += sqrt(double(axis[0]) * axis[0] + double(axis[1]) * axis[1] + double(axis[2]) * axis[2]);
    n++;
  }
  imu.enableReport(SH2_RAW_ACCELEROMETER, 0);
  if (n == 0 || divisor == 0) {
    chk("accel_bits", false, "no raw accelerometer reports arrived");
    return;
  }
  const double countsPerG = magSum / n / divisor;   // steps per g, shift removed
  const double bits = log(16.0 * countsPerG) / log(2.0);  // +-8 g, both signs
  chk("accel_bits", bits > 13.5,
      String(countsPerG, 1) + " steps per g over +-8 g = " + String(bits, 2) +
          " bits (14-bit fusion is BNO086 only; counts are multiples of " +
          String(divisor) + ", the 14-bit field left-aligned in 16), " + String(n) +
          " samples");
}

// The host's wake line: pulling PS0/WAKE low asks a sleeping sensor for a
// transfer, and the sensor answers by asserting INT. Run with no reports
// enabled, so INT is only low because of the request.
void checkWake() {
  // Wait for the sensor to go quiet first.
  const uint32_t start = millis();
  while (millis() - start < 1000) {
    if (digitalRead(kPinInt) == HIGH) break;
    imu.getSensorEvent();  // drain whatever is pending
  }
  if (digitalRead(kPinInt) == LOW) {
    info("wake", "skipped: INT still busy");
    return;
  }
  digitalWrite(kPinWake, LOW);
  const int32_t t = waitInt(kPinInt, LOW, 100);
  digitalWrite(kPinWake, HIGH);
  if (t >= 0) {
    chk("wake", true, "INT answered the wake request in " + String(t) + " ms");
  } else {
    info("wake", "no INT within 100 ms — WAKE may be unwired; not conclusive on its own");
  }
  delay(10);
}

// Which SH-2 features the part admits to having. Genuine CEVA/Hillcrest
// firmware answers all of these; a relabelled or different part will not.
void checkFeatures() {
  struct Feature { const char* name; sh2_SensorId_t id; };
  static const Feature kFeatures[] = {
      {"arvr_stabilized_rv", SH2_ARVR_STABILIZED_RV},
      {"gyro_integrated_rv", SH2_GYRO_INTEGRATED_RV},
      {"stability_classifier", SH2_STABILITY_CLASSIFIER},
      {"magnetometer", SH2_MAGNETIC_FIELD_CALIBRATED},
      {"tap_detector", SH2_TAP_DETECTOR},
  };
  String have;
  for (const Feature& f : kFeatures) {
    const bool ok = imu.enableReport(f.id, 100000);
    imu.enableReport(f.id, 0);  // interval 0 turns the report back off
    have += String(f.name) + "=" + (ok ? "1" : "0") + " ";
    delay(20);
  }
  info("features", have);
}

// A talking sensor is not yet a working one: held still, gravity must read
// ~9.81 m/s^2 and the gyro ~0.
void checkStill() {
  float ax = 0, ay = 0, az = 0, gx = 0, gy = 0, gz = 0;
  uint32_t n = 0, nGyro = 0;
  const uint32_t start = millis();
  while (millis() - start < 2000) {
    if (!imu.getSensorEvent()) continue;
    if (imu.getSensorEventID() == SH2_ACCELEROMETER) {
      ax += imu.getAccelX(); ay += imu.getAccelY(); az += imu.getAccelZ();
      n++;
    } else if (imu.getSensorEventID() == SH2_GYROSCOPE_CALIBRATED) {
      gx += imu.getGyroX(); gy += imu.getGyroY(); gz += imu.getGyroZ();
      nGyro++;
    }
  }
  if (n == 0) {
    chk("still", false, "no accelerometer reports arrived");
    return;
  }
  ax /= n; ay /= n; az /= n;
  if (nGyro > 0) { gx /= nGyro; gy /= nGyro; gz /= nGyro; }
  const float g = sqrtf(ax * ax + ay * ay + az * az);
  const float w = sqrtf(gx * gx + gy * gy + gz * gz);
  chk("still", g > 9.0f && g < 10.6f,
      "|a|=" + String(g, 3) + " m/s^2 over " + String(n) + " accel reports, |w|=" +
          String(w, 4) + " rad/s over " + String(nGyro) +
          " gyro reports (hold it still; |a| should be ~9.81)");
}

}  // namespace

void setup() {
  // Wiring rules 1 and 3: motor gates LOW, then both chip selects high, before
  // anything else.
  for (uint8_t pin : kMotorPins) {
    pinMode(pin, OUTPUT);
    digitalWrite(pin, LOW);
  }
  for (uint8_t pin : {kPinCs, kPinOtherCs}) {
    pinMode(pin, OUTPUT);
    digitalWrite(pin, HIGH);
  }

  // No Serial.begin: the USB endpoint is written directly (see usbWrite).
  // Checks printed before a monitor attaches are kept in `transcript` and
  // re-sent whenever the host sends a byte.
  delay(1500);  // let the host enumerate the USB device
  emit(String("# EAD bench: ") + kSensor + " BNO086 over SPI, DEC-016 wiring");
  char pins[128];
  snprintf(pins, sizeof(pins), "# gpio cs=%u int=%u rst=%u wake=%u sck=%u miso=%u mosi=%u", kPinCs,
           kPinInt, kPinRst, kPinWake, SCK, MISO, MOSI);
  emit(pins);

  if (!checkWiring()) {
    // The SH-2 driver blocks waiting for INT, so do not call it with a dead
    // INT line: the sketch would hang with nothing on the serial port.
    emit("# stopped: the sensor never answered on INT, so SPI was not attempted");
    stopped = true;
    return;
  }

  SPI.begin(SCK, MISO, MOSI, -1);
  if (!imu.beginSPI(kPinCs, kPinInt, kPinRst, kSpiHz)) {
    chk("spi_init", false,
        "no answer over SPI: check SCK/MISO/MOSI/CS, and that the PS0 and PS1 jumpers are open");
    emit("# stopped: fix the wiring and reset the board");
    stopped = true;
    return;
  }
  chk("spi_init", true, "SH-2 opened at " + String(kSpiHz / 1000000) + " MHz, SPI mode 3");
  printIds();
  checkIdentity();
  checkWake();
  checkFeatures();

  const bool rv = imu.enableRotationVector(kReportMs);
  const bool acc = imu.enableAccelerometer(kReportMs);
  const bool gyr = imu.enableGyro(kReportMs);
  chk("reports", rv && acc && gyr,
      String("rotation_vector=") + rv + " accel=" + acc + " gyro=" + gyr);
  check086();
  checkStill();
  emit("# streaming: D,t_ms,qi,qj,qk,qr,acc_deg,ax,ay,az,gx,gy,gz");
}

void loop() {
  if (usbAsked()) usbPrint(transcript);
  if (stopped) {
    delay(100);
    return;
  }

  static float qi = 0, qj = 0, qk = 0, qr = 1, accDeg = 0;
  static float ax = 0, ay = 0, az = 0, gx = 0, gy = 0, gz = 0;

  if (imu.wasReset()) {
    info("reset", "sensor reset itself; re-enabling reports");
    imu.enableRotationVector(kReportMs);
    imu.enableAccelerometer(kReportMs);
    imu.enableGyro(kReportMs);
  }
  if (!imu.getSensorEvent()) return;

  switch (imu.getSensorEventID()) {
    case SH2_ROTATION_VECTOR: {
      qi = imu.getQuatI(); qj = imu.getQuatJ(); qk = imu.getQuatK();
      qr = imu.getQuatReal();
      accDeg = imu.getQuatRadianAccuracy() * 57.29578f;
      // One line per orientation report; accel and gyro carry their latest value.
      char line[160];
      const int n = snprintf(line, sizeof(line),
                             "D,%lu,%.4f,%.4f,%.4f,%.4f,%.1f,%.3f,%.3f,%.3f,%.3f,%.3f,%.3f\n",
                             (unsigned long)millis(), qi, qj, qk, qr, accDeg, ax, ay, az, gx, gy,
                             gz);
      usbWrite(line, n);
      break;
    }
    case SH2_ACCELEROMETER:
      ax = imu.getAccelX(); ay = imu.getAccelY(); az = imu.getAccelZ();
      break;
    case SH2_GYROSCOPE_CALIBRATED:
      gx = imu.getGyroX(); gy = imu.getGyroY(); gz = imu.getGyroZ();
      break;
    default:
      break;
  }
}

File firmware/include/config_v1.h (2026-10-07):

#pragma once
// EAD-V1 fixed configuration values.
// Source of truth: ead_agent_docs_v2/CONFIG_V1.json
// (mirrors 00_README.md / 01_SYSTEM_SPEC.md / 03_GPIO_PIN_MAP.md /
//  04_SENSOR_CALIBRATION_AND_ORIENTATION.md / 05 / 06 / 08 / 09).
// Do NOT invent new sensors, GPIOs, thresholds, or mechanisms.
// Explicitly OUT OF SCOPE in V1: battery ADC, switch GPIO, BLE, FSRs.
// Recorded deviations: the pin map is DEC-016 (two BNO086 on SPI), the sensors
// and their scales DEC-017, motor service pulses DEC-018.

#include <stdint.h>

// ---- Device identity ----
#define EAD_DEVICE_NAME       "EAD-V1"
#define EAD_LIMB              "RIGHT_LEG_ONLY"
#define EAD_FOOTWEAR          "BAREFOOT"

// ---- GPIO map (DEC-016; replaces doc 03 and CONFIG_V1.json "pins") ----
// Both BNO086 boards share SCK, MISO, MOSI, RST and WAKE (= PS0); each has its
// own CS and INT (docs/wiring_reference.md §3).
#define EAD_PIN_SPI_SCK            7
#define EAD_PIN_SPI_MISO           8
#define EAD_PIN_SPI_MOSI           9
#define EAD_PIN_FOOT_CS            43
#define EAD_PIN_SHANK_CS           44
#define EAD_PIN_FOOT_INT           39
#define EAD_PIN_SHANK_INT          40
#define EAD_PIN_SENSOR_RST         41
#define EAD_PIN_SENSOR_WAKE        3
// Motor n is the motor at band position n (EAD_MOTOR_Mn_DEG). Rewired by the user
// on 2026-10-07 (DEC-029): the same six pins, in a new order, with M5 and M6 then
// swapped at the user's request. Until then M1-M6 were GPIO 1, 2, 42, 4, 5, 6
// (D0, D1, MTMS, D3, D4, D5).
#define EAD_MOTOR_M1_GPIO          4   // D3
#define EAD_MOTOR_M2_GPIO          6   // D5
#define EAD_MOTOR_M3_GPIO          42  // back pad MTMS
#define EAD_MOTOR_M4_GPIO          5   // D4
#define EAD_MOTOR_M5_GPIO          2   // D1
#define EAD_MOTOR_M6_GPIO          1   // D0
#define EAD_MOTOR_COUNT            6
// Bit n-1 = motor n may be driven. A channel whose wiring is in doubt is switched
// off here: motor 3 was, until GPIO42 measured about 100 kOhm to GND (PROB-020).
#define EAD_MOTOR_ENABLED_MASK     0x3Fu

// ---- Sensors: BNO086 (DEC-017; replaces CONFIG_V1.json "mpu6050") ----
#define EAD_SPI_HZ                 1000000u  // wiring rule 5: 1 MHz until soak-tested
// 200 Hz frames: the fastest setting both sensors deliver completely on the
// 1 MHz bus (TEST-054, DEC-021). The hub gives the gyroscope and game rotation
// vector 5000 us and the accelerometer 4000 us (250 Hz) for this request.
#define EAD_SAMPLE_HZ              200u
#define EAD_REPORT_INTERVAL_US     5000u
#define EAD_ACCEL_RANGE_G          8         // BMA280 inside the BNO086 (TEST-040)
#define EAD_GYRO_RANGE_DPS         2000      // BMI055 inside the BNO086 (TEST-040)
// Calibrated reports: accelerometer Q8 m/s^2, gyroscope Q9 rad/s. As counts per
// g and per deg/s, so the processing chain keeps its units (DEC-007).
#define EAD_ACCEL_LSB_PER_G        2510.5024f  // 256 * 9.80665
#define EAD_GYRO_LSB_PER_DPS       8.9360858f  // 512 * pi / 180
// Full scale in counts, from the sensors' own metadata (TEST-040).
#define EAD_ACCEL_FULL_SCALE       20082
#define EAD_GYRO_FULL_SCALE        17863

// ---- Coordinate frame (doc 04) ----
// X+ forward toward toes, Y+ medial/left (right leg), Z+ up.
// This anatomical frame is right-handed (X x Y = Z), and so is the sensor
// frame. Any rigid mounting is therefore a proper rotation: a mount map with
// determinant -1 is physically impossible and would make gyro rates disagree
// with accel-derived tilt (see docs/problems.md PROB-002).

// ---- Mount maps: anatomical = M * chip, for accel AND gyro ----
struct EadMountMap {
  int8_t m[3][3];
};

constexpr int eadMountDet(const EadMountMap& a) {
  return a.m[0][0] * (a.m[1][1] * a.m[2][2] - a.m[1][2] * a.m[2][1]) -
         a.m[0][1] * (a.m[1][0] * a.m[2][2] - a.m[1][2] * a.m[2][0]) +
         a.m[0][2] * (a.m[1][0] * a.m[2][1] - a.m[1][1] * a.m[2][0]);
}

// True when M * M^T = I, i.e. every row and column holds exactly one +-1.
constexpr bool eadMountIsSignedPermutation(const EadMountMap& a) {
  for (int r = 0; r < 3; r++) {
    for (int c = 0; c < 3; c++) {
      int dot = 0;
      for (int k = 0; k < 3; k++) dot += a.m[r][k] * a.m[c][k];
      if (dot != (r == c ? 1 : 0)) return false;
    }
  }
  return true;
}

// Measured on the leg for the BNO086 boards (TEST-051, 2026-10-02): standing
// still gives the up axis, a held toe raise and a held seated knee extension the
// forward axis, Y = Z x X. Maps are measured, never derived from statements or
// images (PROB-002). The MPU6500 build's maps are in docs/hardware.md (TEST-027).
// Foot: X = -chipY, Y = +chipX, Z = +chipZ.
constexpr EadMountMap kEadFootMount = {{{0, -1, 0}, {1, 0, 0}, {0, 0, 1}}};
// Shank: X = +chipZ, Y = +chipX, Z = +chipY.
constexpr EadMountMap kEadShankMount = {{{0, 0, 1}, {1, 0, 0}, {0, 1, 0}}};
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

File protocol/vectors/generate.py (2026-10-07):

#!/usr/bin/env python3
"""Generate EAD-V1 protocol golden vectors (schema 7).

These bytes are built independently of the firmware: Python `struct`, `zlib`
and `hashlib`, a separate COBS implementation, and the contract JSON for the
configuration section. Firmware native tests and the dashboard tests compare
their encoders/decoders against these files, so a bug has to be made twice,
in two languages, to go unnoticed.

Layouts: docs/protocol.md.  Run:  python3 protocol/vectors/generate.py
"""
import hashlib
import json
import math
import pathlib
import struct
import zlib

HERE = pathlib.Path(__file__).resolve().parent
ROOT = HERE.parent.parent
CONFIG_JSON = ROOT / "ead_agent_docs_v2" / "CONFIG_V1.json"

PROTOCOL_VERSION = 1
SCHEMA = 9

# Message types (doc 08 §3).
HELLO, CONFIG_GET, STATUS, ERROR = 0x01, 0x02, 0x0C, 0x0E
RAW_SAMPLE_BATCH, BACKFILL_REQUEST, BACKFILL_DATA = 0x08, 0x10, 0x11
RAW_ACCEL_BATCH = 0x13
SESSION_START, SESSION_STOP = 0x04, 0x05
EVENT_BATCH, STEP_BATCH = 0x09, 0x0A
SERVICE_TEST = 0x12
CONFIG_SET, HAPTIC_BATCH = 0x03, 0x0B
ACK = 0x0D
SESSION_EVALUATION = 4

# Calibration states and reject bits (docs/protocol.md §5.3, §6.5).
CALIB_READY = 2
GAIT_FOOT_FLAT = 4
CALIB_MOVED = 1 << 1

# RAW frame status bits (docs/protocol.md).
RAW_FOOT_READ_FAIL, RAW_SHANK_READ_FAIL, RAW_SHANK_REPEATED = 1 << 0, 1 << 1, 1 << 2
RAW_FOOT_ACCEL_SAT, RAW_FOOT_GYRO_SAT = 1 << 3, 1 << 4
RAW_SHANK_ACCEL_SAT, RAW_SHANK_GYRO_SAT, RAW_FOOT_ACCEL_HELD = 1 << 5, 1 << 6, 1 << 7
RAW_ORIENTATION_VALID, RAW_SHANK_ACCEL_HELD = 1 << 8, 1 << 9
RAW_FOOT_RV_MISSING, RAW_SHANK_RV_MISSING = 1 << 10, 1 << 11

# STATUS fault bits (docs/protocol.md).
FAULT_FOOT_FROZEN, FAULT_SHANK_FROZEN, FAULT_ACQUISITION_STALLED = 1 << 7, 1 << 8, 1 << 9
STATE_READY = 4
LINK_USB_ACTIVE = 1 << 0
CAP_PSRAM_RING = 1 << 2
CAP_MOTOR_SERVICE_TEST = 1 << 3
SENSOR_ANSWERED = 0x86

# Sensors and pins of the BNO086 build (DEC-016, DEC-017); they replace the
# contract JSON's "mpu6050" and "pins" groups, so they are written out here.
SENSOR_KIND_BNO086 = 1
SPI_HZ = 1_000_000
# 200 Hz frames (DEC-021, TEST-054): as built, not the contract's 100 Hz.
SAMPLE_HZ = 200
REPORT_INTERVAL_US = 5_000
ACCEL_RANGE_G, GYRO_RANGE_DPS = 8, 2000
# Calibrated SH-2 reports: accelerometer Q8 m/s^2, gyroscope Q9 rad/s.
ACCEL_LSB_PER_G = 256 * 9.80665
GYRO_LSB_PER_DPS = 512 * math.pi / 180
# SCK, MISO, MOSI, foot CS, shank CS, foot INT, shank INT, RST, WAKE; motors M1-M6.
SENSOR_PINS = (7, 8, 9, 43, 44, 39, 40, 41, 3)
# Motors as rewired on 2026-10-07 (DEC-029); until then (1, 2, 42, 4, 5, 6).
MOTOR_PINS = (4, 6, 42, 5, 2, 1)
# Measured on the leg for the BNO086 boards (config_v1.h, TEST-051).
FOOT_MOUNT = [[0, -1, 0], [1, 0, 0], [0, 0, 1]]
SHANK_MOUNT = [[0, 0, 1], [1, 0, 0], [0, 1, 0]]
HAPTICS_FITTED = 1  # DEC-023: error-driven feedback runs
HAPTICS_SWITCH_ON = 1 << 0  # STATUS haptics (schema 7)


def header(msg_type, payload_len, seq, time_us, flags=0):
    return struct.pack("<HBBIIQ", PROTOCOL_VERSION, msg_type, flags, payload_len, seq, time_us)


def message(msg_type, payload, seq, time_us):
    return header(msg_type, len(payload), seq, time_us) + payload


def str8(text):
    raw = text.encode("utf-8")
    assert len(raw) <= 255
    return struct.pack("<B", len(raw)) + raw


def cobs_encode(data):
    """Cheshire & Baker reference algorithm (emits a trailing 0x01 block after
    an exact 254-byte run; any conforming decoder accepts it)."""
    out = bytearray([0])
    code_index, code = 0, 1
    for byte in data:
        if byte == 0:
            out[code_index] = code
            code_index, code = len(out), 1
            out.append(0)
            continue
        out.append(byte)
        code += 1
        if code == 0xFF:
            out[code_index] = code
            code_index, code = len(out), 1
            out.append(0)
    out[code_index] = code
    return bytes(out)


def usb_frame(msg):
    return b"\x00" + cobs_encode(msg + struct.pack("<I", zlib.crc32(msg))) + b"\x00"


def raw_frame(ts, index, foot, shank, q_foot, q_shank, rv_foot, rv_shank, status):
    return struct.pack("<QI6h6h4h4h4h4hH", ts, index, *foot, *shank, *q_foot, *q_shank,
                       *rv_foot, *rv_shank, status)


IDENTITY_Q15 = (32767, 0, 0, 0)
IDENTITY_Q14 = (16384, 0, 0, 0)


def raw_batch_payload(frames):
    return struct.pack("<BB", len(frames), 70) + b"".join(frames)


def accel_batch_payload(samples):
    """RAW_ACCEL_BATCH (docs/protocol.md §5.15): (time, sensor, sequence, ax, ay, az)."""
    return struct.pack("<BB", len(samples), 16) + b"".join(
        struct.pack("<QBB3h", *s) for s in samples)


def config_section_format1(cfg):
    """The MPU6500 build's section (format 1), as stored with every session
    recorded before schema 5: hosts must keep reading it."""
    m, p = cfg["mpu6050"], cfg["pins"]
    out = bytearray()
    out += struct.pack(
        "<BBIHBHBBBff",
        int(m["foot_address"], 16), int(m["shank_address"], 16), m["i2c_hz"], m["sample_hz"],
        m["accelerometer_range_g"], m["gyroscope_range_dps"], m["dlpf_hz"], m["dlpf_cfg"],
        m["sample_rate_divider"], 8192.0, 65.5)  # MPU-6500 sensitivities at +-4 g, +-500 dps
    # The MPU6500 build's mount maps, measured on the leg (TEST-027).
    for mount in ([[1, 0, 0], [0, 1, 0], [0, 0, 1]], [[0, 0, -1], [0, 1, 0], [1, 0, 0]]):
        out += struct.pack("<9b", *[v for row in mount for v in row])
    motors = p["motor_pwm_gpio"]
    out += struct.pack("<10B", p["i2c_sda_gpio"], p["i2c_scl_gpio"], p["foot_imu_int_gpio"],
                       p["shank_imu_int_gpio"], *[motors[f"M{i}"] for i in range(1, 7)])
    # Everything after the pins is the same in both formats. In format 2 it
    # starts after 22 bytes of sensor fields, 18 of mount maps and 15 of pins.
    return bytes(out) + config_section(
        cfg, cfg["zupt"]["gyro_threshold_dps"], haptics_fitted=0,
        haptic_off=cfg["error"]["haptic_off_threshold"],
        haptic_duty=(cfg["haptics"]["min_duty"], cfg["haptics"]["max_duty"]))[22 + 18 + 15:]


# The ZUPT gyroscope limit of the current build: 30 deg/s by the user's decision
# (DEC-020), not the contract's 25. Format 1 keeps 25: its sessions used it.
ZUPT_GYRO_DPS = 30.0


# Feedback as built: an episode ends under the ON threshold (DEC-025), and cues are
# scaled over 60..100 % duty (DEC-026, the user). Format 1 keeps the contract's values.
HAPTIC_OFF_THRESHOLD = 0.35
HAPTIC_DUTY = (153, 255)
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

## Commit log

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2026-09-17 Fix MPU6500 init (WHO 0x70): config now sticks, |a|=1.0g; shank remap + RAW/DIAG
    [config_v1.h, main.cpp]
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2026-09-17 M0: fix shank mount map and MPU6500 accel filter; first Tauri build
    Firmware
    - Shank chip->anatomical map was a reflection (det -1); correct proper
    rotation is X=-chipZ, Y=+chipX, Z=-chipY. Maps are now matrices with
    compile-time signed-permutation and determinant checks (PROB-002, DEC-009).
    - MPU6500 silicon filters accel via ACCEL_CONFIG2 (0x1D), which was never
    written; set it to 0x03 and read back every config register (PROB-003).
    - Drive motor GPIOs LOW before anything else; remove the motor test and PWM
    setup (no drivers fitted, DEC-006).
    - Pin espressif32 @ 7.1.3, build as gnu++17, drop unused Adafruit MPU6050
    and links2004 WebSockets dependencies and duplicated USB flags.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
    [config_v1.h, main.cpp, main.rs]
2026-09-17 M1 firmware data path + M2 dashboard foundation
    - 100 Hz acquisition clocked by the foot IMU data-ready interrupt (IRAM ISR,
    monotonic timestamp, frame index), with a 1-2 ms guard after the edge: reads
    started on the edge fail intermittently (PROB-007).
    - doc-08 binary protocol over both links. Wi-Fi uses ESP-IDF esp_http_server
    and sends only when the socket is writable (DEC-010); USB drives the
    Serial/JTAG endpoint directly, one packet at a time, with Arduino Serial
    unused and core logging compiled out (PROB-006).
    - ~12 minutes of telemetry in a PSRAM ring, addressable by sequence number, so
    a host can backfill anything it missed.
    - lib/ead_core builds for device and h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
    [acquisition.cpp, config.rs, config_v1.h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]
2026-09-17 Docs: traceability for the four clinical requirements
    Maps each requirement in Critical Clinical Insights.docx to the specification
    that defines it, the code that implements it, and the test that proves it.
    Three of the four (ZUPT, per-step error score, patient baseline) are specified
    and scheduled but not yet built; the raw-capture half of the fourth is built
    and verified, while the export files are M6.
2026-09-17 M2 complete: raw-data view over recorded sessions
    Reading recordings back
    - One decimated query groups frames into buckets reporting each bucket's
    minimum and maximum, so a single-frame impact survives decimation; ranges
    below 4,000 frames are returned exactly.
    - Counts convert to anatomical physical units in Rust, using the configuration
    stored with that session, so the view holds no mount-map knowledge and a
    recording made under different settings still reads correctly.
    - Schema 2: sessions carry the device configuration section, making a recording
    of raw counts self-describing. Migration from schema 1 is tested.
    Measured rather than assumed: a full-session query over an hour ta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
    [main.rs]
2026-09-17 Raw view: timeline navigation and all signals at once
    Overview strip with the visible window marked, drag-to-select on any chart,
    pan/zoom buttons and arrow/+/- keys. All four signal groups stacked on a shared
    time axis with a synced cursor, served by one multi-group query (whole session
    542 -> 291 ms, zoomed 78 -> 35 ms on an hour of data, TEST-026).
    Window arithmetic in timeline.ts, tested with node --test (10 tests).
    Fixes two clippy findings left in M2's raw.rs.
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2026-09-17 Correct the shank mount map from on-leg measurement (TEST-027)
    Standing still put gravity on anatomical Y (+0.99 g) and a knee extension turned
    about anatomical Z (+43 deg/s): Y and Z were interchanged. New map
    X = -chipZ, Y = +chipY, Z = +chipX, still a proper rotation, flashed and
    confirmed over USB.
    The mounting check's still step now verifies axis and sign and reports the tilt
    angle: a strap over the instep holds the board at 33 degrees, which calibration
    removes.
    [config_v1.h, generate.py]
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2026-09-17 M3: static calibration on the device (protocol schema 2)
    Five seconds of stillness gives each sensor's gyro bias and the direction of
    gravity, measured on the device from the frames already being acquired.
    SESSION_START/SESSION_STOP carry it, STATUS reports progress, and the dashboard
    and eadprobe can both run it.
    Two faults found on hardware and fixed: a completed record was delivered to the
    next host to connect as though it answered that host's request; and a window
    longer than the 3 s host timeout produced no record because eadprobe sent no
    keepalive while waiting.
    TEST-028: 3 s -> 300 samples, 8 s -> 800, bias repeatable within 0.03 deg/s.
    PROB-009 recorded: the foot accelerometer read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
    [generate.py, link.cpp, main.rs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]
2026-09-17 M3: Mahony orientation on the device, ankle angles in the dashboard
    6-DoF Mahony per IMU (Kp 2.0, Ki 0.05, 100 Hz) starting from the calibrated
    alignment, relative orientation inverse(q_shank)*q_foot, and the three ankle
    angles shown in a sagittal canvas view.
    Orientation refuses rather than guesses: no calibration record or a frame
    interval outside half to twice nominal leaves the quaternions identity and the
    new orientation_valid status bit clear.
    [acquisition.cpp, main.rs, test_main.cpp]
2026-09-17 Fix PROB-010: apply the calibration alignment to the measurements
    The alignment was only the estimator's starting attitude, so the estimate
    described the board, not the segment: a flat foot read -34 degrees, matching the
    instep mounting tilt. Rotating acceleration and angular rate by the alignment
    before the Mahony update brings the neutral pose to -0.11 degrees.
2026-09-17 M4: gait events, ZUPT and cycle distance, tuned on a measured course
    Doc 05 state machine, events, zero-velocity windows and per-cycle features in
    ead_core, carried by schema 3 as EVENT_BATCH and STEP_BATCH. tools/replay runs
    the device's own code over a recording so thresholds can be tested against real
    signals.
    TEST-030 on a 6.00 m course: contact times match ground truth exactly, 6 cycles
    for 6 strides, total distance 6.39 m (+6.5 percent), ZUPT quality 0.22-0.29.
    Four defects found by that recording and fixed: every impact opening a cycle,
    zero-velocity locked out by the PRE_SWING state, push-off read as a footfall,
    and a real contact rejected for lasting 29.96 ms against a 30 ms rule.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
    [generate.py, main.cpp]
2026-09-17 Store gait cycles and events, and show them in a Cycles view
    Schema 3 adds cycles and events tables, keyed so a backfilled batch replaces
    rather than duplicates, and kept separate from raw_frames because a corrected
    detector produces different cycles from the same recording.
    The view reports distance only where ZUPT quality is adequate and greys rejected
    cycles rather than hiding them.
    [main.rs]
2026-09-17 M5 core: reference profiles and the error engine
    Median/MAD reference statistics with per-feature spread floors, and doc 06's
    weighted error score, six classes and five confidence subscores. 11 native tests
    against hand-computed cases.
    The four values doc 06 leaves undefined are chosen and justified in DEC-013
    rather than invented silently.
    [test_main.cpp]
2026-09-17 M5: reference capture, locking, and per-cycle error scoring (schema 4)
    Session kinds carry the locked profile they judge against, so the device scores
    against the profile the operator chose rather than whatever it saw last. A
    capture refuses to produce a profile from fewer than thirty valid cycles, and the
    database refuses to modify a profile once it has been used.
    STEP_BATCH gains the error score, confidence, five subscores, seven deviations
    and the class set; all zero means not scored, which a reader must not confuse
    with agreement.
    [generate.py, link.cpp, main.rs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]
2026-09-17 M5 UI: references, error display, events lanes, and host-side segments
    The dashboard side of the reference workflow. REFERENCES captures a profile
    with progress against the thirty-cycle gate, lists versions with their lock
    state, shows each feature's median and spread, and runs the ten-cycle check.
    CYCLES gains the score, confidence, class and segment of each cycle, and the
    session's class distribution. EVENTS draws the detector's decisions as lanes.
    Segments are counted on the host (DEC-014), superseding the firmware
    enforcement DEC-004 planned: nothing on the device behaves differently at a
    segment boundary in V1, so the rule lives where the limits are entered and
    applies to the stored cy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
    [main.rs]
2026-09-17 M6: CSV, metadata and MATLAB export, and the three things it needed first
    Doc 10 §2-§7. Exporting exposed three gaps in what was being kept: the
    unilateral cycle symmetry proxy had never been implemented, the calibration
    record lived only in device RAM, and faults were not recorded at all. Schema 6
    adds the last two; the proxy is computed on the host from the stored cycle
    stream, and is null rather than zero wherever there are no reference spreads to
    normalize by.
    events.csv derives the doc 10 types the device does not emit -- cycle bounds,
    error transitions, faults -- and says in metadata.json why SERVICE_TEST never
    appears and why ZUPT_END is written although the doc does not list it.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
    [main.rs]
2026-09-17 M6: the PDF research report, and with it the whole export package
    Three A4 pages composed on a fixed grid with krilla: session identity and
    measures with the error-score distribution and class counts; the seven trend
    plots doc 10 §8 requires; the event timeline, segments and data quality. Charts
    are drawn as vectors, so the file is 22 kB and its text is selectable.
    The bundled IBM Plex woff files cannot be read by krilla, so the latin subsets
    are committed as TTF. Embedding the faces the UI already uses keeps a printed
    number identical to the one on screen and keeps a non-Latin-1 patient name from
    becoming question marks.
    The haptic-response plot is drawn empty and labelled rather than om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
2026-09-18 Separate setup scripts for macOS and Windows, with an opt-in install mode
    scripts/setup-macos.sh and scripts/setup-windows.ps1 each check that
    platform's dependencies and, with `install`, offer to install each missing one
    (Homebrew/rustup on macOS, winget on Windows), asking before every item. The
    Linux script is renamed setup-linux.sh.
    Platform details handled rather than left for the first run to find:
    - macOS ships bash 3.2 and a `sort` without -V, so version comparison is done
    in awk and empty arrays are guarded under set -u.
    - Windows PowerShell 5.1 turns a native command's redirected stderr into a
    terminating error under ErrorActionPreference=Stop, so the script uses
    Continue an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
2026-09-18 Repository is public: scripts run straight from GitHub
    The setup scripts now run with a one-liner from raw.githubusercontent.com, and
    the private-repo authentication paths are gone. Two things that only matter
    once a script is piped: under `curl | bash` stdin is the script itself, so the
    macOS install prompt reads from /dev/tty; and a PowerShell scriptblock's
    `exit` closes the user's terminal, so the Windows one-liner downloads to a
    file and runs it in its own process.
    setup-windows.ps1 is pure ASCII (Windows PowerShell 5.1 reads BOM-less UTF-8
    as ANSI) and .gitattributes keeps .ps1 CRLF and .sh LF.
    Also corrects docs/clinical_requirements.md: Critical Clinical Insights.docx
    has been track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
2026-09-18 Fix: the device refused every reference check and evaluation
    SESSION_START for a check or an evaluation carries the 64-byte reference
    profile after its 4-byte head. decodeSessionStart accepted only 4 bytes, so
    the device answered every one with BadPayload and never started scoring; the
    first real check walk recorded 13 valid cycles and scored none. The golden
    vector for this message existed, but its test skipped the head and decoded
    only the profile. The new test decodes the whole message and fails on the old
    decoder.
    The refusal was also silent. The dashboard now waits briefly after starting a
    capture, check or evaluation: a refusal fails the Start button with the
    device's reason, stops th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
    [link.cpp, test_main.cpp]
2026-09-18 Ankle angles ignore heading drift; distance scored only at ZUPT >= 0.15
    The first working reference check classified nearly every normal stride as
    eversion. Recomputing the angles from the stored quaternions showed the foot
    and shank filters' headings drifting 40-60 degrees apart within ten minutes --
    a 6-DoF filter has no heading reference -- and peak inversion tracking that
    drift. relativeOrientation now turns the foot onto the shank's heading before
    composing, on the device and in the dashboard, so the ankle angles rest on
    each segment's tilt against gravity. Within one calibration that brings the
    per-session inversion medians from 18-28 to 16-20 degrees.
    It does not explain a further ~1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
    [test_main.cpp]
2026-09-18 Gait: a floor on stance, so the foot slap is not read as toe-off
    Reference version 3 had a median cycle of 0.86 s against ~1.35 s strides.
    After a heel strike the foot slaps flat as fast as it lifts off; that was
    taken as toe-off, and the real push-off then passed as the next contact,
    splitting about half the strides in two. Toe-off now needs 0.25 s of stance
    after the last contact.
    Chosen by replaying the stored walk through the device code: any floor from
    0.15 s fixes it, 0.25 s is where the benefit levels off. The 6 m ground-truth
    course is unchanged (6 cycles, 6.39 m); the v3 check goes from 18 split
    strides to 0. New test verified to fail without the floor. PROB-016.
    63 firmware tests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
    [main.cpp, test_main.cpp]
2026-09-22 Bench project for one BNO086: wiring checks, identity, tilt viewer
    firmware/bench/bno086 is a separate PlatformIO project, on purpose: it uses
    SparkFun's BNO08x library (CEVA's SH-2 driver), so a failing bench test means
    the wiring, not new code of ours, and the product build keeps its rule of no
    external libraries. It reads every line back with a pull-up and a pull-down
    while the sensor is held in reset, times INT after reset release, answers a
    WAKE request, reads the SH-2 product ID, probes the CEVA-only features, and
    streams rotation vector, accel and gyro at 100 Hz.
    tools/bno_view.py prints those checks and draws a block that tilts with the
    sensor. Its quaternion maths is checked agains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
    [main.cpp]
2026-09-22 Verify the BNO086-only features the datasheet lists
    The part now reports what hardware it contains (Bosch BMA280, BMI055, BMM150,
    external crystal) and answers the two BNO086-only interfaces: the Motion Intent
    command and the Motion Request report of Interactive Calibration. The
    accelerometer's resolution is measured rather than assumed: 1120 steps per g over
    +-8 g, 14.1 bits, which is the 14-bit fusion the datasheet says only the BNO086
    has.
    The first version of that resolution test was wrong and would have called a
    14-bit part 12-bit: the BMA280 puts its 14-bit value left-aligned in a 16-bit
    field, so counts arriving as multiples of 4 is correct, not a fault. TEST-040 and
    the progress ent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
    [main.cpp]
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2026-10-01 GPIO39 must never drive a motor, and the tool that proves it
    The question was whether the four back pads can be PWM outputs. Three can.
    GPIO39 cannot: the ESP32-S3 datasheet marks MTCK with footnote 7 -- with
    EFUSE_DIS_PAD_JTAG unburnt, which is the default, the pad comes out of reset
    with its weak pull-up enabled. At 45 kOhm against the contract's 100 kOhm gate
    pulldown that is 2.3 V on the gate, well over the IRLML6344's threshold, so a
    motor there would run from power-up until firmware intervened, and would stay on
    in download mode or a hung bootloader. GPIO40, 41 and 42 have no pull at or
    after reset, are not strapping pins and are not in the power-up glitch table.
    Section 14 of the wir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
    [main.cpp]
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2026-10-01 Docs back to the actual state; PROB-019 recorded
    The docs described the 2026-09-18 state: M3-M6 "not started", schema 1,
    the old shank map, "nobody has walked thirty cycles", no DEC for the
    two-sensor pin map. They now say what is true on 2026-10-02: M0-M6 built
    on the MPU6500 build, patient-67 references unusable (PROB-016), the
    physical device rewired to DEC-016 and not supported by the product
    firmware, which must not be flashed onto it.
    TEST-034's "18 vectors" was a miscount (17 at its own commit), corrected
    in place. The firmware error texts no longer name a schema number.
    PROB-019 (open): a device reboot during a recording leaves the host
    session open, so new-boot frames are dropped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
    [link.cpp]
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2026-10-02 TEST-043: both BNO086s pass on the DEC-016 wiring; power hazard recorded
    Each sensor, flashed in turn with the bench firmware at 1 MHz: INT idle in
    reset, boot 112 ms after RST, SH-2 answers over SPI, WAKE answered in 1 ms,
    genuine BNO086 (3.12.6, 14-bit accel), |a| 9.94 and 9.81 m/s^2 still,
    streaming at 99.8 Hz. Every one of the nine lines per sensor took part in
    a passing step. GPIO42 was left undriven (PROB-020), which the sensor
    test does not need.
    PROB-021: the switched battery feeds the XIAO's 5V pin, which Seeed says
    is USB VBUS with no diode, so with USB plugged in USB 5 V meets the
    charger's LOAD+ when the master switch is ON. Rule until it is changed:
    never switch ON while USB is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
    [main.cpp]
2026-10-02 BNO086 product firmware, SERVICE_TEST and ead --check (schema 5)
    Own two-sensor SH-2 driver on the DEC-016 pins (DEC-017): per-wire boot
    check, gyro-clocked 100 Hz frames (the accelerometer runs at 125 Hz),
    lost-report accounting, sensor-reset recovery. Motor service pulses timed
    on the device within the contract limits (DEC-018); motor 3 refused until
    PROB-020 is measured. Config format 2; format 1 kept readable for stored
    sessions (store schema 7 adds config_format and a service-test log).
    Dashboard Check view, opened by `ead --check`: per-wire table for both
    sensors, live rates to tell foot from shank, per-motor pulse with a felt
    answer. eadprobe gains check and pulse.
    Verified over USB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
    [acquisition.cpp, bno086.cpp, config.rs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]
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2026-10-02 PROB-019: a device reboot ends the host session; verified on hardware
    A changed boot_id after an earlier one now clears the host's session kind
    and ends the store's recording (segments closed as device_restarted),
    because the new boot restarts frame indices and would mix into or
    overwrite the old boot's data. The state bar says "<session> ended:
    device restarted" until another session starts. A replug of the same
    boot ends nothing.
    New ignored hardware test: calibrate and record, replug (both survive),
    reset the board with esptool (the session ends, the calibration is gone
    and the gate blocks). PASS, which completes TEST-042 (PROB-018).
    PROB-022 (open): still on the desk, both gyroscopes s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
    [main.rs]
2026-10-02 Motor 3 enabled: GPIO42 measures 100 kOhm to GND (PROB-020 resolved)
    The user measured the MTMS pad to GND on the unpowered board: about
    100 kOhm, steady, the gate network every motor pin sees. That rules out
    every faulty-wiring hypothesis; the earlier "held low" readback is a pin
    pulled to about 2.3 V, inside the band the chip does not guarantee to
    read either way. GPIO42 now goes LOW at boot with the others and motor 3
    accepts service pulses; the bench firmware no longer skips it.
    Flashed: motor service test available, sensor check 14/14 PASS, 15 s at
    100.143 Hz with nothing missing. Whether motor 3 turns is for the user
    to feel.
    [config_v1.h, link.cpp, main.cpp]
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2026-10-02 PROB-024: soft footfalls confirmed by stillness; 20 Hz event path for ZUPT
    A swing that ends in stillness claims its strongest late impact as the
    contact; the stillness test reads |a| through doc 04's 20 Hz event path.
    On the five 10 m walks: contacts 86 -> 92 of 92 counted, uncorrected
    cycles 8 -> 5, no new split strides; the 6 m walk is unchanged (DEC-019,
    TEST-053). Slow strides still read 30 % short (open).
    [test_main.cpp]
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2026-10-04 TEST-058: barefoot 10 m walks over Wi-Fi at 200 Hz, synced with video
    Seven fixtures from 2026-10-04 with sync offsets; the replay takes
    --still-from for recordings that do not start still. 0 frames lost over
    Wi-Fi; the contact detector splits strides (PROB-024). Videos stay local.
    [main.cpp]
2026-10-04 Gait events from the shank's swing (DEC-022, TEST-059)
    One contact per shank swing of 100 deg/s or more, timed at the foot's
    strongest impact around the swing's downward zero crossing; toe-off at the
    deepest backward shank rate before the swing. Counting error on the walk
    fixtures 21 -> 3 over 176 counted landings, no split strides. TEST-030's
    first heel strike was a push-off (correction recorded).
    [main.cpp, test_main.cpp]
2026-10-04 Haptic feedback during evaluations (DEC-023, protocol schema 7, store schema 10)
    One vibration cue per scored step, after it lands, decided on the device by
    a new HapticEngine (doc 06: gating, two-motor direction, intensity,
    hysteresis) and held to the motor guard's limits. Master switch: CONFIG_SET
    haptic_feedback, off at every boot, reported in STATUS and shown in the
    dashboard's top bar. Every cue and episode end travels as HAPTIC_BATCH and
    is stored and exported (haptics.csv, MAT, PDF). Host-tested (TEST-060);
    not yet flashed or felt.
    [config.rs, config_v1.h, feedback.cpp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]
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2026-10-04 Dashboard: LIVE cycle metrics, doc 11's seven trends, CYCLES to RAW, vibration column and lane
    [main.rs]
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2026-10-05 Audit fixes: sensor faults stop feedback, serialized motor and session state, contact angle at impact, every calibration adopted
    PROB-026, PROB-027, PROB-028; TEST-063.
    [acquisition.cpp, main.cpp, motors.cpp]
2026-10-05 Store: a failed commit keeps and retries its batches, and says so (PROB-029)
    [main.rs]
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2026-10-05 DEC-025: full-strength 0.5 s cues, OFF at 0.35, spread floors raised and applied at scoring
    The user's choice after TEST-066/067: faint cues, episodes running on, and normal
    walking buzzing against a steady reference.
    [config_v1.h, feedback.cpp, generate.py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]
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2026-10-06 Second audit fixes: calibration record kept until sent, Wi-Fi silence and backfill, session attribution, store schema 12, NaN guards
    PROB-037 to PROB-042 (audit F-27, F-29, F-28, F-36, F-30, F-33, F-34, F-35, F-37,
    F-13, F-39, F-22); F-16 mirrored constants tested against the firmware; F-21, F-23,
    F-25 docs, stray file, root README.
    [link.cpp, test_main.cpp]
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2026-10-07 DEC-029 update: M5 and M6 swapped at the user's request (M5 D1, M6 D0)
    [config_v1.h, generate.py]
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2026-10-08 PROB-043/044: a timestamp slightly behind no longer restarts gait; distances beyond walking are not scored; PROB-045 recorded
    [test_main.cpp]
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
